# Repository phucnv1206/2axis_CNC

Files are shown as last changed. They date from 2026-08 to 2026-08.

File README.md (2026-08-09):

## Overview
This is a simple 2-axis CNC plotter that uses a servo motor to raise and lower the pen, and 28BYJ-48 stepper motors with GT2 belts for movement. Drawing area: 120 x 120 mm.

The machine’s motion design is inspired by the Bambu Lab A1 Mini 3D printer. The entire frame is designed and 3D-printed.

This project was developed for educational purposes, so it is not designed for high precision. All components are common and readily available, making the project easy and affordable to build.

This is the first version of the project, so there are still some known issues that have not yet been fixed. **Please use the machine with caution.**

---

## Features
- Quick and easy connection
- Connect to the plotter quickly with a simple setup process.
- Simple image-to-line conversion
- Start drawing quickly without the need for complex or in-depth configuration.
- Large drawing area for a wide range of drawing projects.

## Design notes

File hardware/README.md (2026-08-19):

## Mechanical Design

It is designed in Autodesk Inventor 2020, all part is printed by BambuLab A1 Mini.

## BOM

- Step motor 28BYJ-48: 2 pcs
- Driver ULN2003 : 2 pcs
- Esp32 Devkit: 1 pcs
- Limit switch: 2 pcs
- Servo EMAX ES08MA: 1 pcs
- Fan 50x50mm : 1pcs

## POWER

Using 5v power supply from usb for all devices.

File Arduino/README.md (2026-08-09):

## Firmware on Arduino Ide
In case you don't use platform io, you can use this code on Arduino Ide to upload code.

In Arduino Ide, you use Default Settings to upload. No need to change.

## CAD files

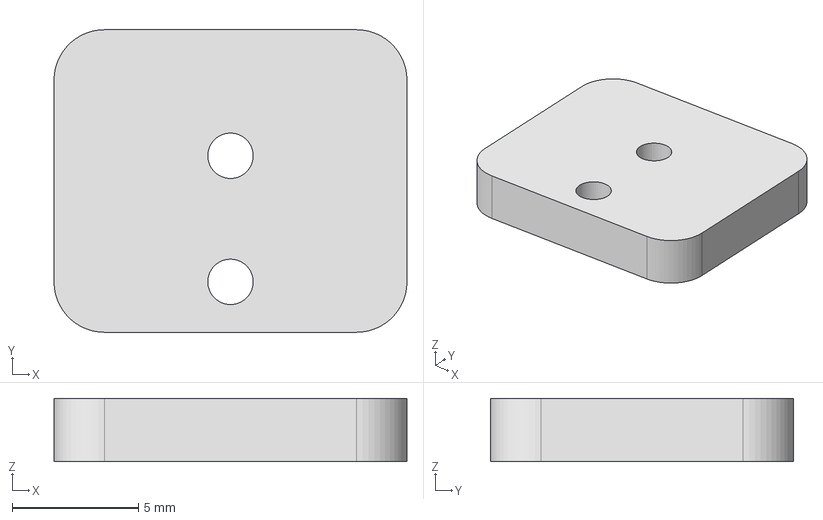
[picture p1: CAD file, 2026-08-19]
hardware/3D_model_Step/hold gt2.stp
14.0 x 12.0 x 2.50 mm

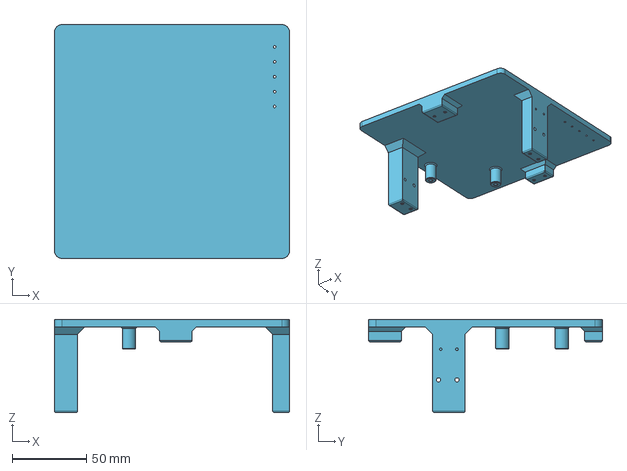
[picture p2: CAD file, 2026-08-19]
hardware/3D_model_Step/frame.stp
157.8 x 157.0 x 62.5 mm

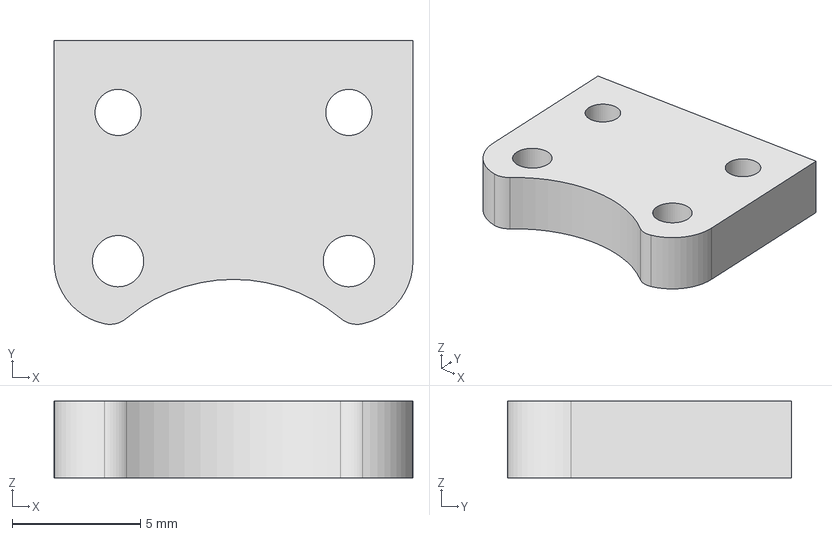
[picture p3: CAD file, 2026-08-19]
hardware/3D_model_Step/upper slider pen.stp
14.0 x 11.1 x 3.00 mm

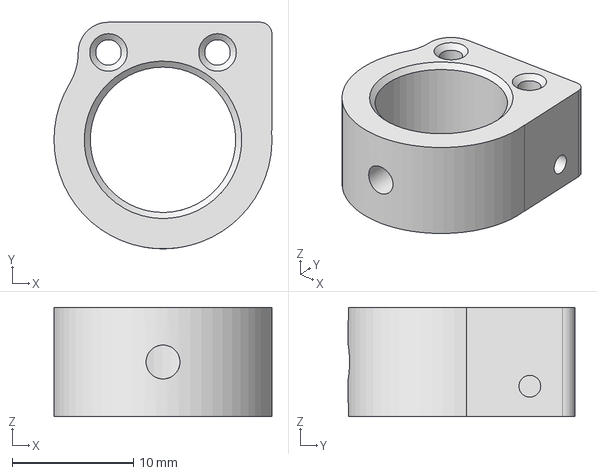
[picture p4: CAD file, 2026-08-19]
hardware/3D_model_Step/hold pen - slider pen.stp
18.0 x 18.7 x 9.00 mm

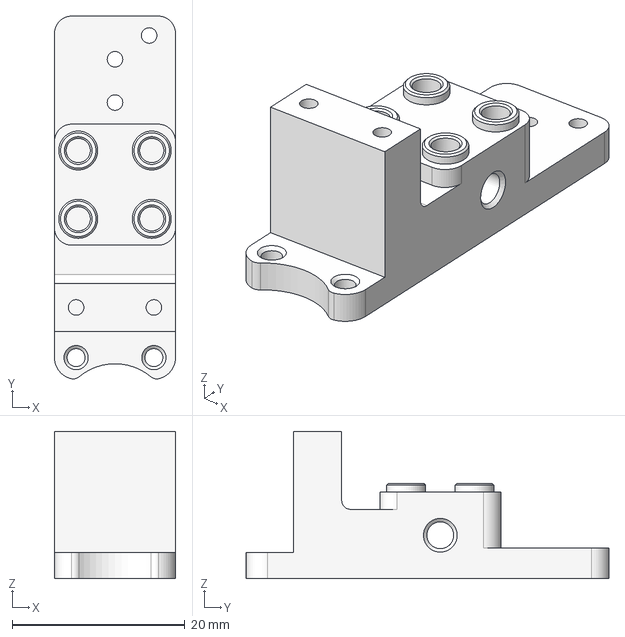
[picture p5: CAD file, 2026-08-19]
hardware/3D_model_Step/slider.stp
14.0 x 42.0 x 17.0 mm

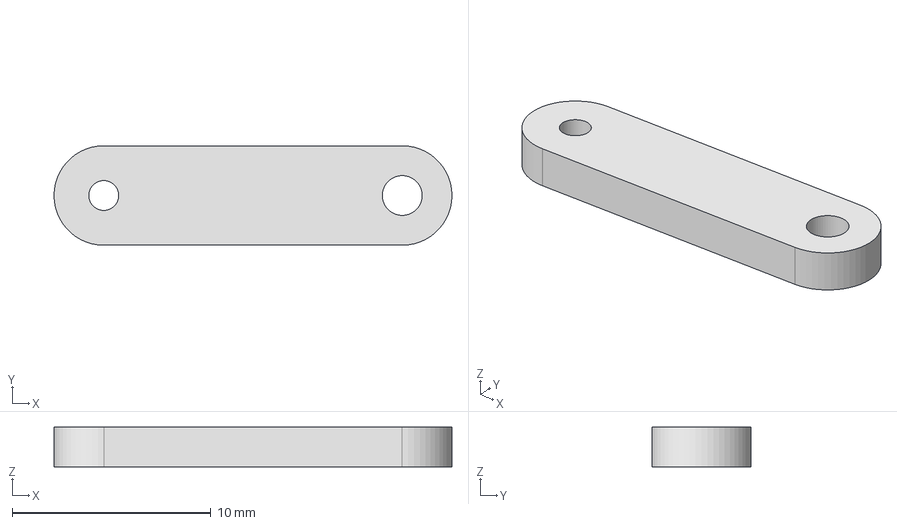
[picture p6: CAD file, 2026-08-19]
hardware/3D_model_Step/horn slider pen.stp
20.0 x 5.00 x 2.00 mm

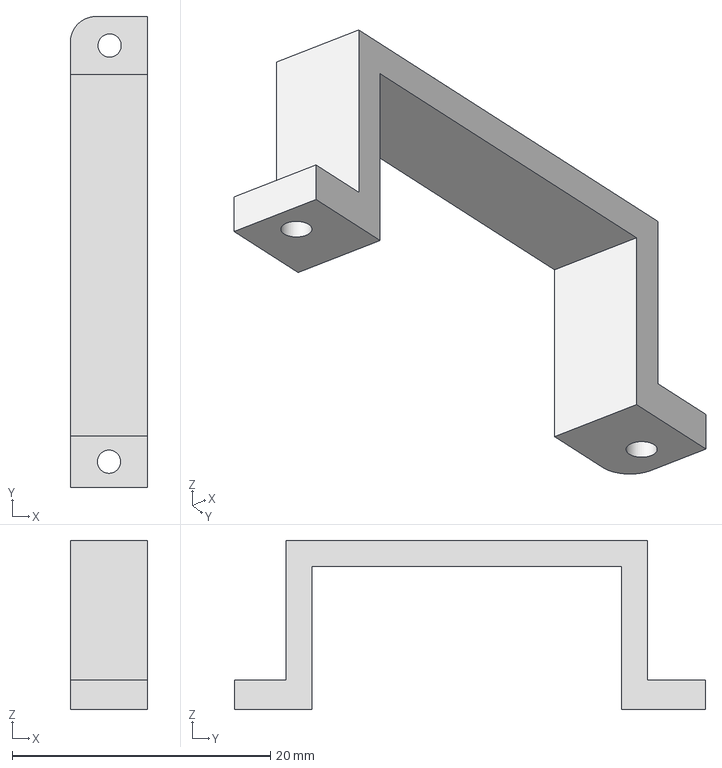
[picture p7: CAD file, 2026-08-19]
hardware/3D_model_Step/holder servo.stp
6.00 x 36.5 x 13.1 mm

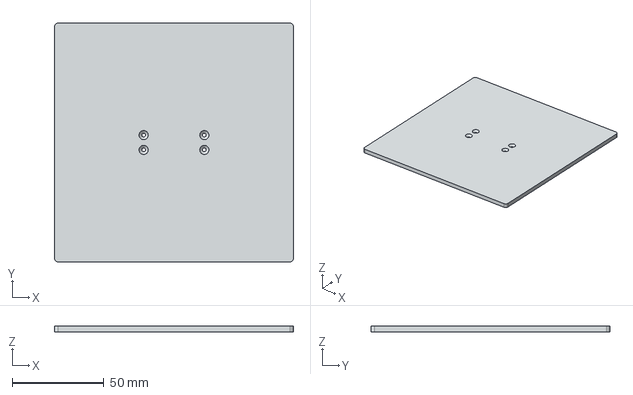
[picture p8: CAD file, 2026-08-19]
hardware/3D_model_Step/plate.stp
130.0 x 130.0 x 3.00 mm

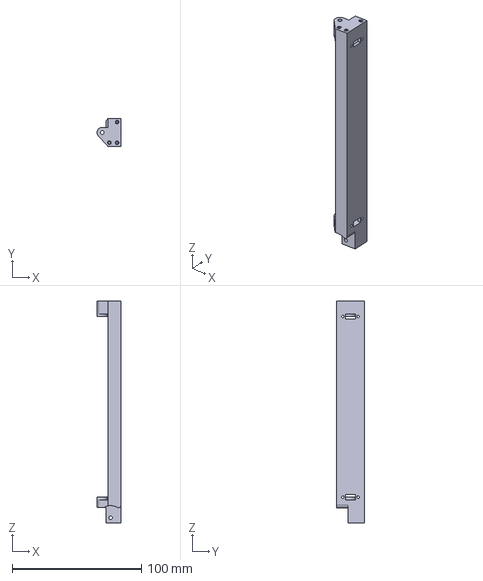
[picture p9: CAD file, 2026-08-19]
hardware/3D_model_Step/slide rail.stp
18.5 x 21.8 x 172.0 mm

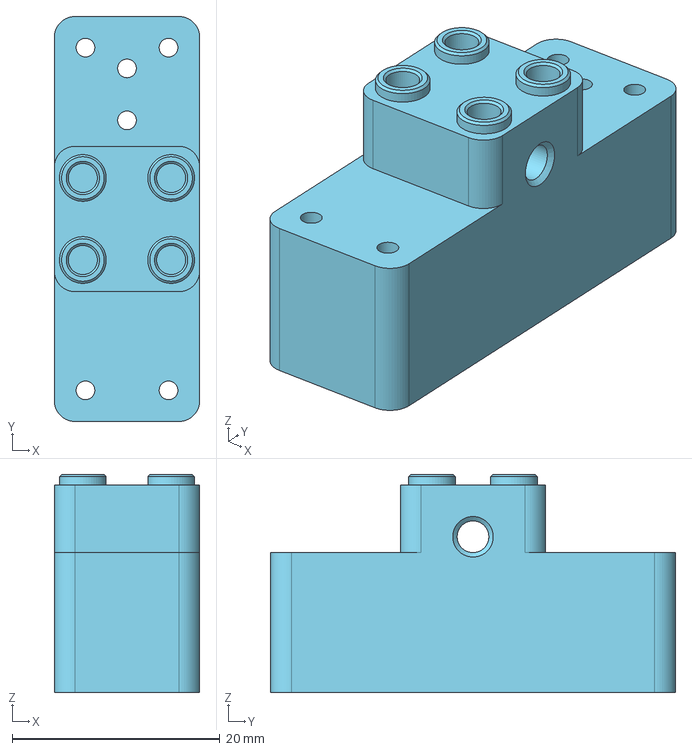
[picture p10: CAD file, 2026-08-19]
hardware/3D_model_Step/slider Y.stp
14.0 x 39.0 x 21.0 mm

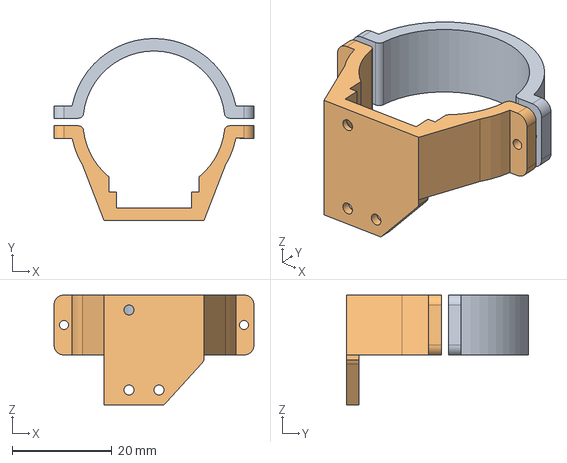
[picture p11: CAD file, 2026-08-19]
hardware/3D_model_Step/motor holder.stp
40.0 x 36.4 x 22.0 mm

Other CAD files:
hardware/3D_model_inventor/border pen.ipt
hardware/3D_model_inventor/frame.ipt
hardware/3D_model_inventor/hold gt2.ipt
hardware/3D_model_inventor/hold pen - slider pen.ipt
hardware/3D_model_inventor/holder servo.ipt
hardware/3D_model_inventor/horn slider pen.ipt
hardware/3D_model_inventor/motor holder.ipt
hardware/3D_model_inventor/plate.ipt
hardware/3D_model_inventor/servo horn.ipt
hardware/3D_model_inventor/slide rail.ipt
hardware/3D_model_inventor/slider Y.ipt
hardware/3D_model_inventor/slider.ipt
hardware/3D_model_inventor/upper slider pen.ipt

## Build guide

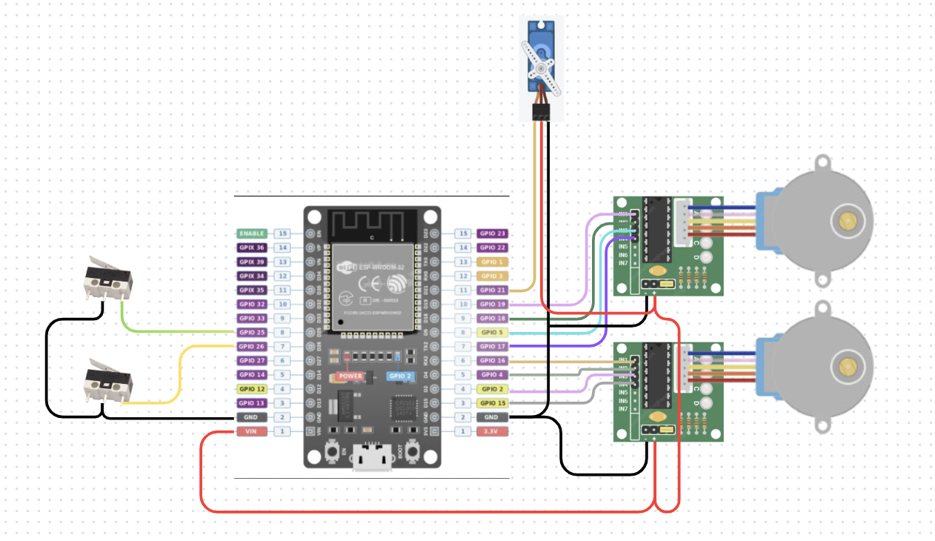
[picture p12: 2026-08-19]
hardware/Wiring Diagrams/wiring.png

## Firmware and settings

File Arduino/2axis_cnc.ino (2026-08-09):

#include <ESP32Servo.h>

Servo sv;

#define X_axis 26
#define Y_axis 25

// 2048 step/rotation
// 0.0194565 mm/step => steps/mm = 51.4
#define STEPS_PER_MM 51.4f
#define AXIS_LIMIT_MM 120
#define MAX_STEPS ((long)(AXIS_LIMIT_MM * STEPS_PER_MM))  // ~5140 steps

//================= Pen raise/lower Servo =================
#define SERVO_PIN 21
#define PEN_UP_ANGLE 75     // pen raised, not touching paper
#define PEN_DOWN_ANGLE 96  // pen lowered, touching paper

//================= Motor 1 (X axis) =================
const uint8_t motor1Pins[4] = { 15, 2, 4, 16 };

//================= Motor 2 (Y axis) =================
const uint8_t motor2Pins[4] = { 17, 5, 18, 19 };

// Full-step sequence (4 states)
const uint8_t stepTable[4][4] = {
  { 1, 1, 0, 0 },
  { 0, 1, 1, 0 },
  { 0, 0, 1, 1 },
  { 1, 0, 0, 1 }
};

int stepIndex1 = 0;
int stepIndex2 = 0;

void outputMotor(const uint8_t pins[], int index) {
  for (int i = 0; i < 4; i++)
    digitalWrite(pins[i], stepTable[index][i]);
}

// dir = -1 : run in positive direction (increase position, move away from home)
// dir =  1 : run in negative direction (decrease position, move towards home switch)
void stepMotorX(int dir) {
  stepIndex1 += dir;
  if (stepIndex1 >= 4) stepIndex1 = 0;
  if (stepIndex1 < 0) stepIndex1 = 3;
  outputMotor(motor1Pins, stepIndex1);
}

void stepMotorY(int dir) {
  stepIndex2 += dir;
  if (stepIndex2 >= 4) stepIndex2 = 0;
  if (stepIndex2 < 0) stepIndex2 = 3;
  outputMotor(motor2Pins, stepIndex2);
}

#define STEP_PERIOD_MIN_US 2500    // us/step, fastest speed (~300Hz) - travel & coarse homing
#define STEP_PERIOD_MEDIUM_US 3333  // us/step, medium speed (~111Hz) - backing off switch
#define STEP_PERIOD_MAX_US 5000    // us/step, slowest speed (80Hz) - precise re-homing
#define RAMP_STEPS 60              // number of steps for acceleration/deceleration on straight path (F)
#define HOME_RETRACT_STEPS 60      // minimum retract steps away from switch to fully release button
#define HOME_PASSES 1               // number of retract + re-probe passes to determine precise home position

#define IDLE_DISABLE_MS 500UL  // ms of inactivity -> disable motor phases to save power/prevent heating

uint32_t lastTime = 0;
uint32_t lastMoveTime = 0;
bool motorsEnabled = true;

//======================= Current position (in steps, 0 = home) =======================
long posX = 0;
long posY = 0;

//======================= Linear interpolation state (Bresenham) =======================
struct MotionState {
  bool active = false;
  bool xIsMajor = true;  // axis with larger step count -> step every tick
  long stepsMajor = 0;   // total steps for major axis (ticks needed to complete)
  long stepsMinor = 0;   // total steps for minor axis
  long counted = 0;      // ticks executed
  long error = 0;        // Bresenham error accumulator
  int dirX = 1;
  int dirY = 1;
  bool rampIn = true;   // flag to accelerate at start of command
  bool rampOut = true;  // flag to decelerate at end of command
} motion;

long targetX = 0;
long targetY = 0;

//======================= Flag indicating home drift check is needed after full stop =======================
bool needDriftCheck = false;

//======================= Prototypes =======================
void startMove(long tx, long ty, bool verbose = true, bool rampIn = true, bool rampOut = true);
long mmToSteps(float mm);
uint32_t getCurrentPeriod();
void refineAxis(void (*stepFunc)(int), int switchPin, int passes);
void checkAxisDrift();
void penUp();
void penDown();
void printPos();
void disableMotors();
void enableMotors();

//======================= Report current position to host =======================
void printPos() {
  Serial.print(F("POS:"));
  Serial.print(posX / STEPS_PER_MM, 2);
  Serial.print(F(","));
  Serial.println(posY / STEPS_PER_MM, 2);
}

//======================= Disable/enable motor drive phases when idle =======================
void disableMotors() {
  if (!motorsEnabled) return;
  for (int i = 0; i < 4; i++) {
    digitalWrite(motor1Pins[i], LOW);
    digitalWrite(motor2Pins[i], LOW);
  }
  motorsEnabled = false;
  Serial.println(F("Idle: motor phases disabled."));
}

void enableMotors() {
  if (motorsEnabled) return;
  outputMotor(motor1Pins, stepIndex1);  // restore correct current phase first to avoid step loss
  outputMotor(motor2Pins, stepIndex2);
  motorsEnabled = true;
}

//======================= Pen raise/lower Servo =======================
void penUp() {
  sv.write(PEN_UP_ANGLE);
  Serial.println(F("Pen up."));
  printPos();
}

void penDown() {
  sv.write(PEN_DOWN_ANGLE);
  Serial.println(F("Pen down."));
  printPos();
}

//======================= Sequential fine homing per axis =======================
void refineAxis(void (*stepFunc)(int), int switchPin, int passes) {
  for (int pass = 0; pass < passes; pass++) {
    // 1. Retract from switch until signal is fully released (HIGH)
    int safetyCounter = 0;
    while (digitalRead(switchPin) == LOW && safetyCounter < 1000) {
      stepFunc(-1);  // run in positive direction (away from switch)
      delayMicroseconds(STEP_PERIOD_MEDIUM_US);
      safetyCounter++;
    }

    // Retract a fixed additional distance (HOME_RETRACT_STEPS) to ensure button is fully released
    for (int i = 0; i < HOME_RETRACT_STEPS; i++) {
      stepFunc(-1);
      delayMicroseconds(STEP_PERIOD_MEDIUM_US);
    }

    // 2. Probe back very slowly (negative direction) to find exact contact point
    while (digitalRead(switchPin) == HIGH) {
      stepFunc(1);  // run in negative direction (towards switch)
      delayMicroseconds(STEP_PERIOD_MAX_US);
    }
  }
}

void doHoming() {
  enableMotors();

  // Coarse homing: run BOTH AXES SIMULTANEOUSLY at fastest speed until limit switch is triggered
  Serial.println(F("Coarse homing both axes..."));
  while (digitalRead(X_axis) == HIGH || digitalRead(Y_axis) == HIGH) {
    if (digitalRead(X_axis) == HIGH) stepMotorX(1);  // run in negative direction
    if (digitalRead(Y_axis) == HIGH) stepMotorY(1);  // run in negative direction
    delayMicroseconds(STEP_PERIOD_MIN_US);
  }

  // Fine homing independently per axis
  Serial.println(F("Fine homing X axis..."));
  refineAxis(stepMotorX, X_axis, HOME_PASSES);
  posX = 0;

  Serial.println(F("Fine homing Y axis..."));
  refineAxis(stepMotorY, Y_axis, HOME_PASSES);
  posY = 0;

  delay(200);
}

//======================= Check home position drift after full stop =======================
void checkAxisDrift() {
  bool xSwitchOn = (digitalRead(X_axis) == LOW);
  bool ySwitchOn = (digitalRead(Y_axis) == LOW);

  bool xOk = (xSwitchOn == (posX == 0));
  bool yOk = (ySwitchOn == (posY == 0));

  if (!xOk) {
    Serial.println(F("Warning: X axis position mismatch with switch, re-homing X axis..."));
    refineAxis(stepMotorX, X_axis, 1);
    posX = 0;
  }
  if (!yOk) {
    Serial.println(F("Warning: Y axis position mismatch with switch, re-homing Y axis..."));
    refineAxis(stepMotorY, Y_axis, 1);
    posY = 0;
  }
}

//======================= Motor step & safety check for sudden limit switch triggers =======================
void doStepX() {
  stepMotorX(motion.dirX);
  posX += -motion.dirX;  // dir=-1 (positive dir) -> posX+1 ; dir=1 (negative dir) -> posX-1
  lastMoveTime = millis();

  // Only reset position to 0 if actively moving in negative direction (dirX == 1) and actually hitting switch
  // Avoids false triggers caused by mechanical vibration when starting from position 0
  if (motion.dirX == 1 && posX < 10 && digitalRead(X_axis) == LOW) {
    posX = 0;
  }
}

void doStepY() {
  stepMotorY(motion.dirY);
  posY += -motion.dirY;
  lastMoveTime = millis();

  if (motion.dirY == 1 && posY < 10 && digitalRead(Y_axis) == LOW) {
    posY = 0;
  }
}

long mmToSteps(float mm) {
  long s = (long)round(mm * STEPS_PER_MM);
  return constrain(s, 0L, (long)MAX_STEPS);
}

//======================= Initialize straight linear motion to (tx, ty) =======================
void startMove(long tx, long ty, bool verbose, bool rampIn, bool rampOut) {
  enableMotors();

  tx = constrain(tx, 0L, (long)MAX_STEPS);
  ty = constrain(ty, 0L, (long)MAX_STEPS);

  long dX = tx - posX;
  long dY = ty - posY;

  motion.dirX = (dX >= 0) ? -1 : 1;
  motion.dirY = (dY >= 0) ? -1 : 1;

  long stepsX = abs(dX);
  long stepsY = abs(dY);

  targetX = tx;
  targetY = ty;

  if (stepsX >= stepsY) {
    motion.xIsMajor = true;
    motion.stepsMajor = stepsX;
    motion.stepsMinor = stepsY;
  } else {
    motion.xIsMajor = false;
    motion.stepsMajor = stepsY;
    motion.stepsMinor = stepsX;
  }

  motion.error = motion.stepsMajor / 2;
  motion.counted = 0;
  motion.active = (motion.stepsMajor > 0);
  motion.rampIn = rampIn;
  motion.rampOut = rampOut;

  if (!verbose) return;

  if (!motion.active) {
    Serial.println(F("Already at target position, no movement needed."));
    printPos();
  } else {
    Serial.print(F("Starting move to X="));
    Serial.print(tx / STEPS_PER_MM, 2);
    Serial.print(F("mm Y="));
    Serial.print(ty / STEPS_PER_MM, 2);
    Serial.println(F("mm"));
  }
}

//======================= Execute 1 step of Bresenham interpolation =======================
void motionTick() {
  if (!motion.active) return;

  if (motion.xIsMajor) {
    doStepX();
    motion.error -= motion.stepsMinor;
    if (motion.error < 0) {
      doStepY();
      motion.error += motion.stepsMajor;
    }
  } else {
    doStepY();
    motion.error -= motion.stepsMinor;
    if (motion.error < 0) {
      doStepX();
      motion.error += motion.stepsMajor;
    }
  }

  motion.counted++;
  if (motion.counted >= motion.stepsMajor) {
    motion.active = false;
    posX = targetX;
    posY = targetY;
    needDriftCheck = true;
  }
}

//======================= Calculate current tick period (Soft start / stop ramp) =======================
uint32_t getCurrentPeriod() {
  if (!motion.active) return STEP_PERIOD_MIN_US;

  long i = motion.counted;
  long total = motion.stepsMajor;
  long rampLen = min((long)RAMP_STEPS, total / 2);
  if (rampLen <= 0) return STEP_PERIOD_MIN_US;

  long fromStart = motion.rampIn ? i : rampLen;
  long fromEnd = motion.rampOut ? (total - 1 - i) : rampLen;

  long pos = min(fromStart, fromEnd);
  if (pos >= rampLen) return STEP_PERIOD_MIN_US;
  return map(pos, 0, rampLen, STEP_PERIOD_MAX_US, STEP_PERIOD_MIN_US);
}

//======================= Parse commands from Serial Monitor (Circular arc R structure removed) =======================
void parseAndMove(String line) {
  line.trim();
  line.toUpperCase();

  if (line == "D") {
    penDown();
    return;
  }
  if (line == "U") {
    penUp();
    return;
  }
  if (line == "?") {
    printPos();
    return;
  }
  if (line == "H") {
    Serial.println(F("Homing..."));
    doHoming();
    lastMoveTime = millis();
    printPos();
    return;
  }
  if (line == "LIMIT?") {
    Serial.print(F("LIMIT:"));
    Serial.println(AXIS_LIMIT_MM);
    printPos();
    return;
  }

  int xIndex = line.indexOf('X');
  int yIndex = line.indexOf('Y');
  int fIndex = line.indexOf('F');

  if (xIndex == -1 || yIndex == -1 || yIndex < xIndex) {
    Serial.println(F("Invalid syntax. Example: X10 Y20 / X10 Y10 F0 / D / U"));
    printPos();
    return;
  }

  int yEnd = line.length();
  if (fIndex > yIndex && fIndex < yEnd) yEnd = fIndex;

  float xmm = line.substring(xIndex + 1, yIndex).toFloat();
  float ymm = line.substring(yIndex + 1, yEnd).toFloat();

  bool rampIn = true, rampOut = true;
  if (fIndex != -1) {
    int mode = line.substring(fIndex + 1).toInt();
    if (mode < 0 || mode > 3) mode = 3;
    rampIn = (mode == 1 || mode == 3);
    rampOut = (mode == 2 || mode == 3);
  }

  if (xmm < 0 || xmm > AXIS_LIMIT_MM || ymm < 0 || ymm > AXIS_LIMIT_MM) {
    Serial.print(F("Position out of bounds 0-"));
    Serial.print(AXIS_LIMIT_MM);
    Serial.println(F("mm."));
    printPos();
    return;
  }

  long tx = mmToSteps(xmm);
  long ty = mmToSteps(ymm);

  startMove(tx, ty, true, rampIn, rampOut);
}

void handleSerialInput() {
  static String buf = "";
  while (Serial.available()) {
    char c = Serial.read();
    if (c == '\n' || c == '\r') {
      if (buf.length() > 0) {
        parseAndMove(buf);
        buf = "";
      }
    } else {
      buf += c;
    }
  }
}

bool isAnyPhaseOn() {
  for (int i = 0; i < 4; i++) {
    if (digitalRead(motor1Pins[i]) == HIGH) return true;
    if (digitalRead(motor2Pins[i]) == HIGH) return true;
  }
  return false;
}

void setup() {
  Serial.begin(115200);

  for (int i = 0; i < 4; i++) {
    pinMode(motor1Pins[i], OUTPUT);
    pinMode(motor2Pins[i], OUTPUT);
  }

  pinMode(X_axis, INPUT_PULLUP);
  pinMode(Y_axis, INPUT_PULLUP);

  sv.attach(SERVO_PIN);
  penUp();

  doHoming();

  Serial.println(F("Homing completed."));
  lastMoveTime = millis();
  printPos();
}

void loop() {
  uint32_t period = getCurrentPeriod();
  if (micros() - lastTime >= period) {
    lastTime += period;
    motionTick();
  }

  if (!motion.active) {
    if (needDriftCheck) {
      needDriftCheck = false;
      checkAxisDrift();
      lastMoveTime = millis();
      printPos();
    }
    handleSerialInput();

    if (motorsEnabled && (millis() - lastMoveTime > IDLE_DISABLE_MS)) {
      disableMotors();
      if (isAnyPhaseOn()) {
        for (int i = 0; i < 4; i++) {
          digitalWrite(motor1Pins[i], LOW);
          digitalWrite(motor2Pins[i], LOW);
        }
        Serial.println(F("Warning: Force disabled phases manually second time!"));
      }
    }

  } else {
    // Moving: listen for emergency stop 'S'
    while (Serial.available()) {
      char c = Serial.read();
      if (c == 'S' || c == 's') {
        motion.active = false;
        needDriftCheck = false;
        Serial.println(F("EMERGENCY STOP EXECUTED."));
        printPos();
      }
    }
  }
}

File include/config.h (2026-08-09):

#pragma once

// ============================================================
//  config.h  –  Compile-time configuration for 2-axis CNC plotter
//
//  Edit the values in this file to adapt the firmware to your
//  hardware without touching any other source file.
// ============================================================

// ------------------------------------------------------------
//  Mechanical parameters
//  2048 steps/rev, lead-screw pitch => 0.0194565 mm/step
// ------------------------------------------------------------
#define STEPS_PER_MM      51.4f
#define AXIS_LIMIT_MM     120
#define MAX_STEPS         ((long)(AXIS_LIMIT_MM * STEPS_PER_MM))

// ------------------------------------------------------------
//  GPIO – limit switches (active LOW, INPUT_PULLUP)
// ------------------------------------------------------------
#define PIN_X_LIMIT       26
#define PIN_Y_LIMIT       25

// ------------------------------------------------------------
//  GPIO – stepper motors (full-step, 4-wire unipolar/bipolar)
// ------------------------------------------------------------
#define MOTOR_X_PIN1      15
#define MOTOR_X_PIN2       2
#define MOTOR_X_PIN3       4
#define MOTOR_X_PIN4      16

#define MOTOR_Y_PIN1      17
#define MOTOR_Y_PIN2       5
#define MOTOR_Y_PIN3      18
#define MOTOR_Y_PIN4      19

// ------------------------------------------------------------
//  GPIO – pen-lift servo
// ------------------------------------------------------------
#define PIN_SERVO         21
#define PEN_UP_ANGLE      75    // degrees – pen raised
#define PEN_DOWN_ANGLE    96    // degrees – pen on paper

// ------------------------------------------------------------
//  Stepper speed & ramping
// ------------------------------------------------------------
#define STEP_PERIOD_FAST_US    2500   // us/step – travel & coarse home (~400 Hz)
#define STEP_PERIOD_MED_US     3333   // us/step – retract from switch  (~300 Hz)
#define STEP_PERIOD_SLOW_US    5000   // us/step – fine probe            (200 Hz)
#define RAMP_STEPS             60     // accel/decel ramp length (steps)

// ------------------------------------------------------------
//  Homing
// ------------------------------------------------------------
#define HOME_RETRACT_STEPS    60   // extra steps after coarse hit to fully release switch
#define HOME_PASSES            1   // retract + re-probe cycles per axis for fine homing

// ------------------------------------------------------------
//  Idle coil-disable timeout
// ------------------------------------------------------------
#define IDLE_DISABLE_MS   500UL   // ms of inactivity → coils off

// ------------------------------------------------------------
//  Serial
// ------------------------------------------------------------
#define SERIAL_BAUD       115200

// ------------------------------------------------------------
//  MotionState  –  runtime state for one linear move
// ------------------------------------------------------------
struct MotionState {
    bool  active     = false;
    bool  xIsMajor   = true;  // axis with more steps drives the tick loop
    long  stepsMajor = 0;
    long  stepsMinor = 0;
    long  counted    = 0;     // ticks executed so far
    long  error      = 0;     // Bresenham error accumulator
    int   dirX       = 1;     // +1 toward home, -1 away from home
    int   dirY       = 1;
    bool  rampIn     = true;
    bool  rampOut    = true;
};

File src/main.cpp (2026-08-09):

#include <Arduino.h>
#include "config.h"
#include "Stepper.h"
#include "Homing.h"
#include "Motion.h"
#include "SerialComm.h"

// ============================================================
//  Hardware objects
// ============================================================
static const uint8_t PINS_X[4] = { MOTOR_X_PIN1, MOTOR_X_PIN2, MOTOR_X_PIN3, MOTOR_X_PIN4 };
static const uint8_t PINS_Y[4] = { MOTOR_Y_PIN1, MOTOR_Y_PIN2, MOTOR_Y_PIN3, MOTOR_Y_PIN4 };

Stepper motorX(PINS_X);
Stepper motorY(PINS_Y);

// ============================================================
//  Shared state (position, timing)
// ============================================================
long     posX        = 0;
long     posY        = 0;
uint32_t lastMoveMs  = 0;
uint32_t lastTickUs  = 0;

// ============================================================
//  Subsystem controllers
// ============================================================
Motion     motion    (motorX, motorY, PIN_X_LIMIT, PIN_Y_LIMIT, posX, posY);
Homing     homing    (motorX, motorY, PIN_X_LIMIT, PIN_Y_LIMIT, posX, posY);
SerialComm serial    (motion, homing, posX, posY, lastMoveMs);

// ============================================================
//  setup
// ============================================================
void setup() {
    Serial.begin(SERIAL_BAUD);

    // Initialise stepper drivers
    motorX.begin();
    motorY.begin();

    // Limit switches – active LOW, internal pull-up
    pinMode(PIN_X_LIMIT, INPUT_PULLUP);
    pinMode(PIN_Y_LIMIT, INPUT_PULLUP);

    // Attach servo, lift pen
    serial.begin();

    // Home on power-up
    homing.run();

    lastMoveMs = millis();
    serial.printPos();
}

// ============================================================
//  loop
// ============================================================
void loop() {
    // ---- Time-driven step tick ----
    uint32_t period = motion.getCurrentPeriod();
    if (micros() - lastTickUs >= period) {
        lastTickUs += period;
        motion.tick();
    }

    // ---- Post-move drift check ----
    if (motion.needsDriftCheck()) {
        motion.clearDriftFlag();
        homing.checkDrift();
        lastMoveMs = millis();
        serial.printPos();
    }

    // ---- Serial input (idle: full commands | moving: 'S' only) ----
    serial.poll(!motion.isActive());

    // ---- Idle coil-disable ----
    if (!motion.isActive()) {
        bool xCoilsOn = motorX.isEnabled();
        bool yCoilsOn = motorY.isEnabled();

        if ((xCoilsOn || yCoilsOn) &&
            (millis() - lastMoveMs > IDLE_DISABLE_MS))
        {
            motorX.disable();
            motorY.disable();
            Serial.println(F("Idle: motor coils disabled."));

            // Safety: force-verify all pins are LOW
            if (motorX.isAnyCoilOn() || motorY.isAnyCoilOn()) {
                motorX.disable();
                motorY.disable();
                Serial.println(F("Warning: forced second coil-off pass!"));
            }
        }
    }
}

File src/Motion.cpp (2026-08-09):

#include "Motion.h"

// ------------------------------------------------------------
Motion::Motion(Stepper& motorX, Stepper& motorY,
               uint8_t pinXLim, uint8_t pinYLim,
               long& posX, long& posY)
    : _mX(motorX), _mY(motorY),
      _pinX(pinXLim), _pinY(pinYLim),
      _posX(posX), _posY(posY)
{}

// ------------------------------------------------------------
void Motion::begin() {
    // Nothing hardware-specific; MotionState initialised inline.
}

// ------------------------------------------------------------
void Motion::startMove(long tx, long ty,
                       bool verbose,
                       bool rampIn, bool rampOut)
{
    _mX.enable();
    _mY.enable();

    tx = constrain(tx, 0L, (long)MAX_STEPS);
    ty = constrain(ty, 0L, (long)MAX_STEPS);

    long dX = tx - _posX;
    long dY = ty - _posY;

    // dir = -1 → positive (away from home) | dir = +1 → negative (toward home)
    _state.dirX = (dX >= 0) ? -1 : 1;
    _state.dirY = (dY >= 0) ? -1 : 1;

    long stepsX = abs(dX);
    long stepsY = abs(dY);

    _targetX = tx;
    _targetY = ty;

    if (stepsX >= stepsY) {
        _state.xIsMajor   = true;
        _state.stepsMajor = stepsX;
        _state.stepsMinor = stepsY;
    } else {
        _state.xIsMajor   = false;
        _state.stepsMajor = stepsY;
        _state.stepsMinor = stepsX;
    }

    _state.error   = _state.stepsMajor / 2;
    _state.counted = 0;
    _state.active  = (_state.stepsMajor > 0);
    _state.rampIn  = rampIn;
    _state.rampOut = rampOut;

    if (!verbose) return;

    if (!_state.active) {
        Serial.println(F("Already at target, no move needed."));
    } else {
        Serial.print(F("Moving to X="));
        Serial.print(tx / STEPS_PER_MM, 2);
        Serial.print(F("mm  Y="));
        Serial.print(ty / STEPS_PER_MM, 2);
        Serial.println(F("mm"));
    }
}

// ------------------------------------------------------------
void Motion::tick() {
    if (!_state.active) return;

    // Bresenham: major axis always steps; minor axis steps when error < 0
    if (_state.xIsMajor) {
        _doStepX();
        _state.error -= _state.stepsMinor;
        if (_state.error < 0) {
            _doStepY();
            _state.error += _state.stepsMajor;
        }
    } else {
        _doStepY();
        _state.error -= _state.stepsMinor;
        if (_state.error < 0) {
            _doStepX();
            _state.error += _state.stepsMajor;
        }
    }

    _state.counted++;
    if (_state.counted >= _state.stepsMajor) {
        _state.active = false;
        _posX         = _targetX;
        _posY         = _targetY;
        _driftPending = true;
    }
}

// ------------------------------------------------------------
uint32_t Motion::getCurrentPeriod() const {
    if (!_state.active) return STEP_PERIOD_FAST_US;

    long i       = _state.counted;
    long total   = _state.stepsMajor;
    long rampLen = min((long)RAMP_STEPS, total / 2);
    if (rampLen <= 0) return STEP_PERIOD_FAST_US;

    long fromStart = _state.rampIn  ? i               : rampLen;
    long fromEnd   = _state.rampOut ? (total - 1 - i) : rampLen;

    long pos = min(fromStart, fromEnd);
    if (pos >= rampLen) return STEP_PERIOD_FAST_US;

    return (uint32_t)map(pos, 0, rampLen, STEP_PERIOD_SLOW_US, STEP_PERIOD_FAST_US);
}

// ------------------------------------------------------------
void Motion::emergencyStop() {
    _state.active = false;
    _driftPending = false;
    Serial.println(F("EMERGENCY STOP."));
}

// ------------------------------------------------------------
long Motion::mmToSteps(float mm) {
    long s = (long)round(mm * STEPS_PER_MM);
    return constrain(s, 0L, (long)MAX_STEPS);
}

// ------------------------------------------------------------
//  Private step helpers – update position and guard against
//  spurious limit-switch triggers near position 0
// ------------------------------------------------------------
void Motion::_doStepX() {
    _mX.step(_state.dirX);
    _posX += -_state.dirX;   // dir=-1 (pos move) → posX++ | dir=+1 → posX--

    // Snap to 0 only when moving toward home and switch triggers
    if (_state.dirX == 1 && _posX < 10 && digitalRead(_pinX) == LOW) {
        _posX = 0;
    }
}

void Motion::_doStepY() {
    _mY.step(_state.dirY);
    _posY += -_state.dirY;

    if (_state.dirY == 1 && _posY < 10 && digitalRead(_pinY) == LOW) {
        _posY = 0;
    }
}
